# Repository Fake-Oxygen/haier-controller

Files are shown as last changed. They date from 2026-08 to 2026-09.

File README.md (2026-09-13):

# Haier Heat Pump Controller

Custom controller and monitoring interface for Haier heat pumps using the **YR-E27 remote-control interface / Modbus RTU**.

The project combines an embedded controller, custom hardware, firmware, and host-side tools for communicating with and monitoring the heat pump.

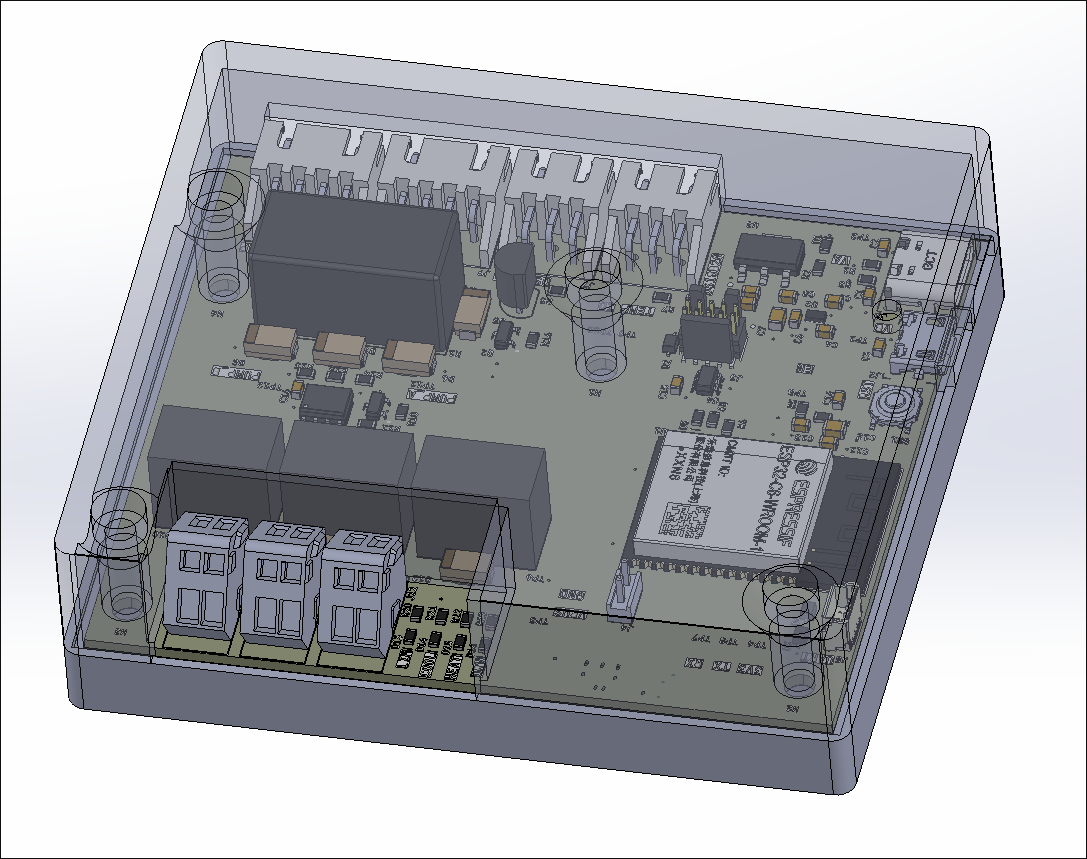
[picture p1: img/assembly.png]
Assembly


## Overview

The controller interfaces directly with the heat pump's communication bus and provides access to operational data and control parameters that are otherwise handled by the original control system.

The system is built around an **ESP32-C6** running **Zephyr RTOS**. The controller communicates with the heat pump over UART/Modbus RTU and exposes selected telemetry and control functionality through Wi-Fi and MQTT.

The repository also contains hardware and mechanical design files, as well as software utilities used for protocol investigation, testing, and monitoring.

## System Architecture

```text
                    ┌─────────────────────┐
                    │    Haier Heat Pump  │
                    │                     │
                    │  YR-E27 / Modbus RTU│
                    └──────────┬──────────┘
                               │
                         UART / RS-485
                               │
                    ┌──────────▼──────────┐
                    │   ESP32-C6          │
                    │                     │
                    │   Zephyr RTOS       │
                    │   Modbus client     │
                    │   Heat pump driver  │
                    │   Control logic     │
                    └───────┬───────┬─────┘
                            │       │
                          Wi-Fi    GPIO
                            │       │
                     ┌──────▼───┐   ├── Relay outputs
                     │   MQTT   │   └── Status / sensors
                     └──────────┘
```

The exact hardware interfaces and signal routing are documented in the hardware design files.

## Heat Pump Communication

The main purpose of the project is direct communication with the Haier heat pump.

Communication uses **Modbus RTU over UART**. The firmware implements the required register access and translates the heat pump's register data into higher-level operating parameters.

The implementation currently provides access to parameters including:

* CH temperature
* DHW temperature
* CH target temperature
* DHW target temperature
* Operating mode
* Valve state
* Tank status
* Heater operating state
* Other system status registers

The firmware can also write supported registers to change selected operating parameters.

The register definitions and protocol implementation are located in the firmware sources.

## Hardware

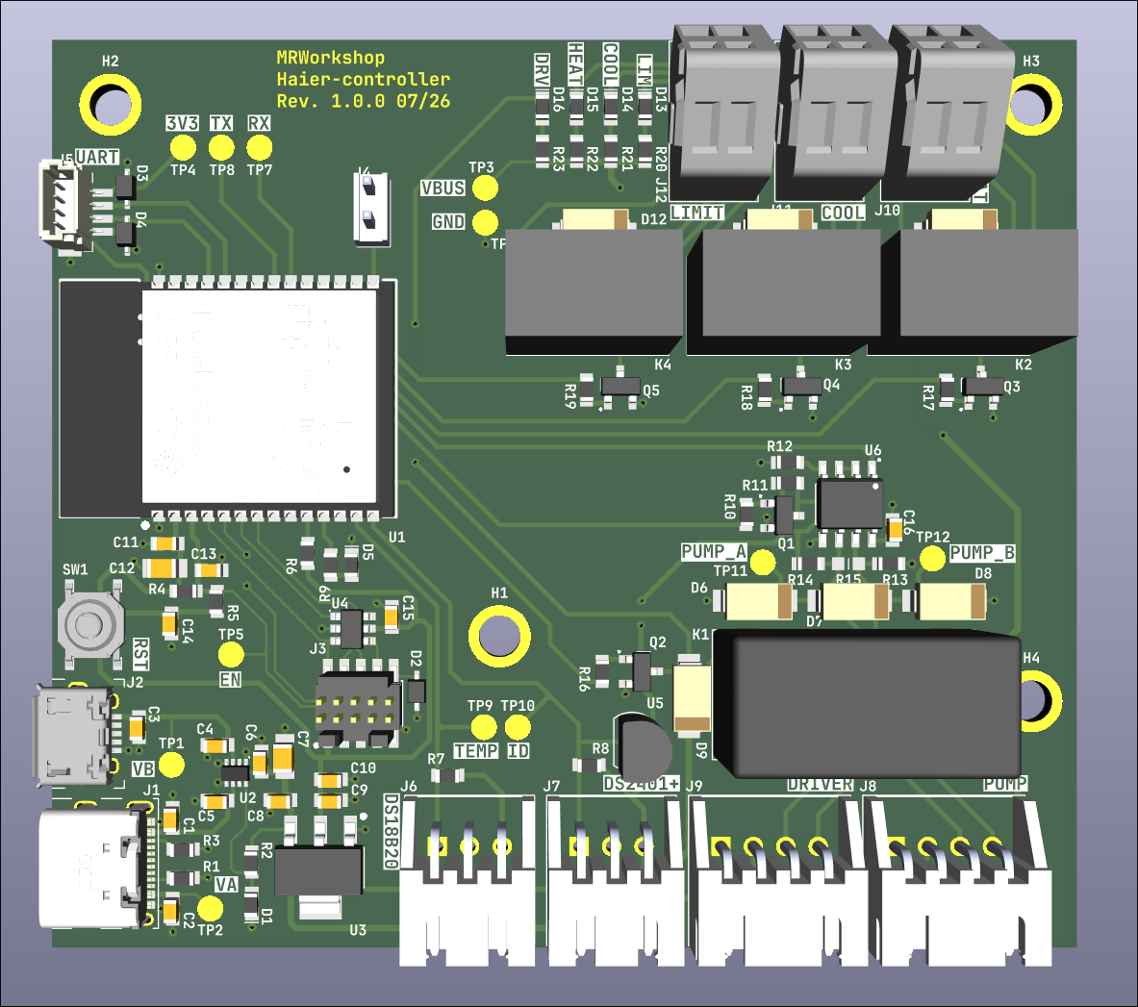
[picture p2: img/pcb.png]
PCB


The controller is based on an **ESP32-C6**.

The hardware provides interfaces for:

* Heat pump communication
* Wi-Fi
* Temperature measurement
* Relay/control outputs
* Status indication

The complete hardware design is located in [`hw/`](./hw).

Refer to the schematics and PCB files there for the actual electrical implementation.

## Mechanical Design

Mechanical parts and enclosure designs are located in [`hwm/`](./hwm).

The enclosure is designed around the controller hardware and its intended installation environment.

Available CAD/manufacturing files should be treated as the authoritative source for dimensions and mechanical details.

## Firmware

The embedded firmware is located in [`fw/`](./fw).

It is written in **C** and uses **Zephyr RTOS**.

The firmware is responsible for:

* Modbus communication with the heat pump
* Register decoding
* Heat pump state/control handling
* Wi-Fi connectivity
* MQTT communication
* Telemetry publishing
* Local I/O such as relays and sensors

The main application and hardware-specific code are organized within the firmware tree.

## MQTT

The controller publishes heat pump telemetry over MQTT, allowing the data to be consumed by external systems such as home-automation or monitoring software.

Telemetry is encoded using **CBOR** before being published.

The MQTT interface is implemented in the firmware and is intended to decouple the heat pump interface from higher-level monitoring and automation systems.

## Host-Side Tools

The [`sw/`](./sw) directory contains software used during development and operation of the system.

These tools are separate from the ESP32 firmware and are useful for tasks such as:

* Monitoring communication
* Testing the heat pump interface
* Experimenting with the protocol
* Simulating heat pump behavior

In particular, `sniffer.py` and `mock_heatpump.py` are used for working with the communication protocol without necessarily relying on the complete embedded system.

## Building the Firmware

The firmware uses the Zephyr build system and `west`.

Initialize the project:

```bash
./init.sh
```

Build for the target board:

```bash
west build -p auto -b esp32c6_devkitc_hpcore
```

Flash the resulting firmware:

```bash
west flash
```

The required Zephyr SDK and Python dependencies must be installed before building.

## Repository Structure

```text
.
├── fw/                  # ESP32-C6 firmware
│   ├── src/             # Application code
│   ├── drivers/         # Hardware / heat pump drivers
│   └── boards/          # Board-specific configuration
│
├── hw/                  # Electronics design
│   ├── ...              # Schematics / PCB files
│   └── ...
│
├── hwm/                 # Mechanical design
│   ├── ...              # CAD / STL files
│   └── ...
│
├── sw/                  # Host-side tools
│   ├── sniffer.py       # Protocol analysis tool
│   ├── mock_heatpump.py # Heat pump simulator
│   └── ...
│
└── README.md
```

## Development Status

This repository contains an actively developed controller and reverse-engineering effort for interfacing with the Haier heat pump communication system.

The firmware, hardware, and host-side tooling are maintained together because development of the controller depends on understanding and testing the heat pump's communication protocol.

For the current implementation status, refer to the firmware and software sources rather than assuming that every documented interface is production-ready.

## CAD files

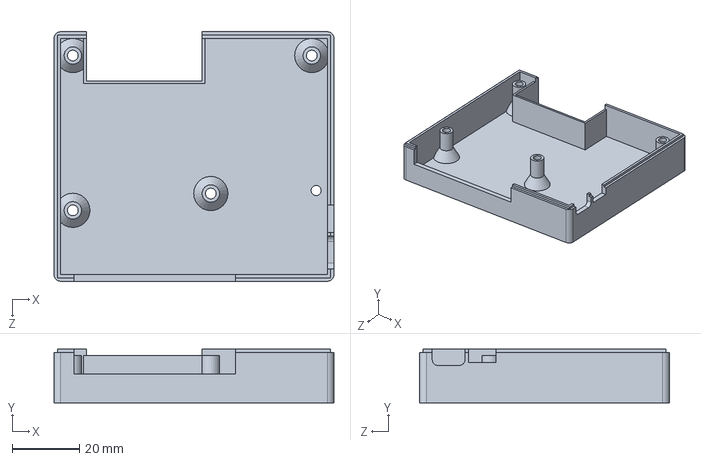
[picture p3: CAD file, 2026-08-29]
hwm/enclosure-top.SLDPRT
83.2 x 15.9 x 74.2 mm

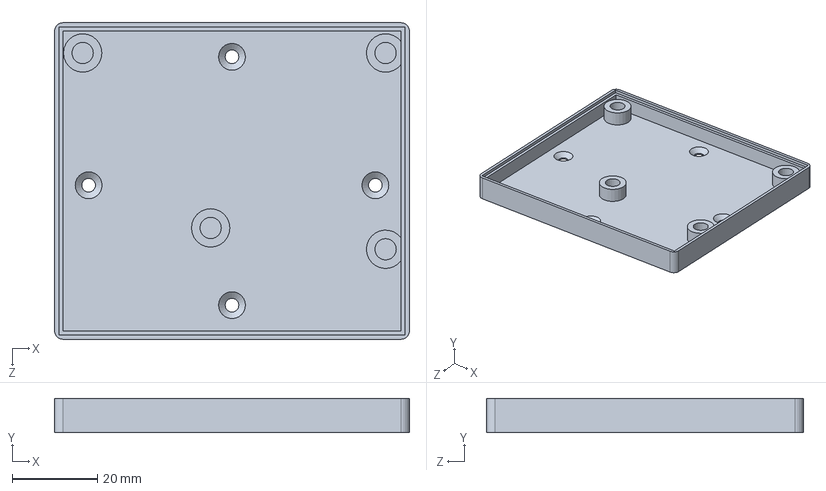
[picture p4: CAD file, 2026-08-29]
hwm/enclosure-bot.SLDPRT
83.2 x 8.00 x 74.2 mm

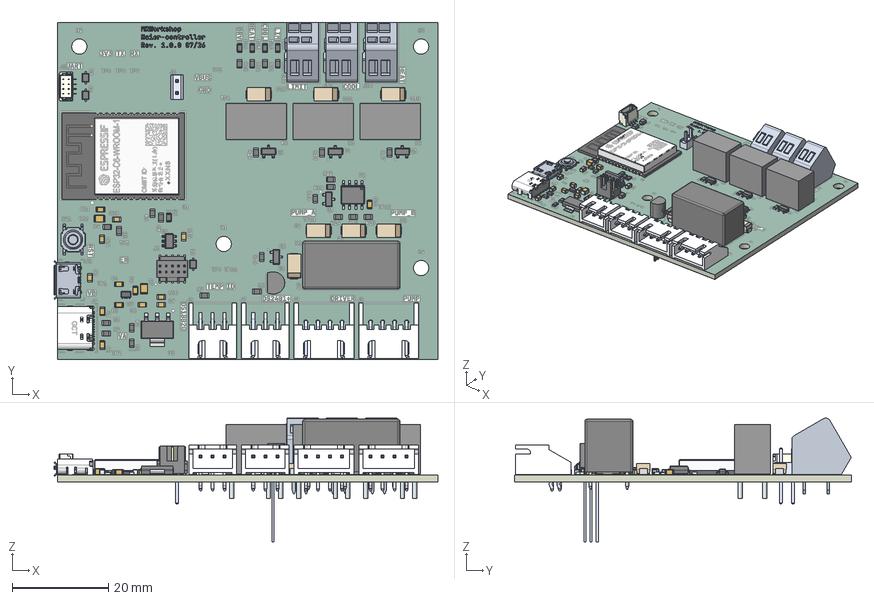
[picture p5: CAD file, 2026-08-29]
hwm/haier-controller-pcb.step
79.8 x 70.0 x 25.7 mm
PCB x 56
Mid Body x 23
Mark x 23
BODY-SOT
Goldpin 2.54 1x2 Vertical
Leader x 29
10118194C
SxB-XH-A_3 x 2
pin^SxB-XH-A ass_bent x 4
pin^SxB-XH-A ass x 2
Leads x 18
BM04B-SRSS-TB(LF)(SN)-PIN
BM04B-SRSS-TB(LF)(SN)-BODY
lead x 6
ESP32-C6-WROOM-1U-N4
DS2401+
Lead x 3
Tab
SxB-XH-Axxxxx_4 x 2
pin^SxB-XH-A-1(LF)(SN)_bent x 4
pin^SxB-XH-A-1(LF)(SN) x 4
HSG_Ĭɏ
FTSH-105-01-L-DV-K
HFD27 005-H
haier-controller-unsaved-export-n6KFfo_silkscreen
haier-controller-unsaved-export-n6KFfo_soldermask x 2
haier-controller-unsaved-export-n6KFfo_PCB

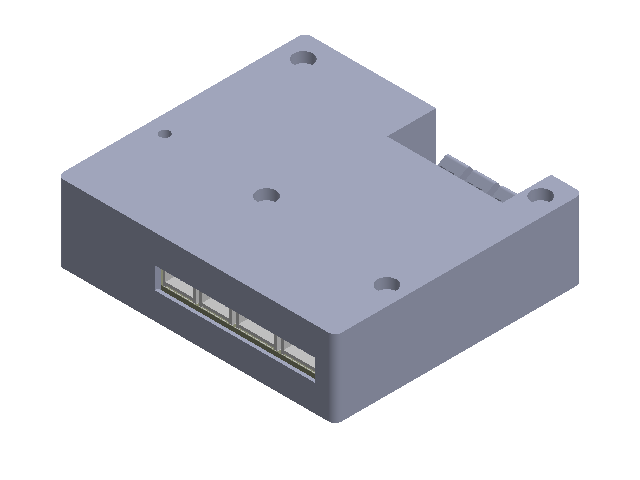
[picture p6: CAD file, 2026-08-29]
hwm/Assembly.SLDASM
enclosure-bot
Mid Body.step x 23
Mark.step x 23
SOLID.step
SOLID-0.step
SOLID-1.step
SOLID-2.step
SOLID-3.step
SOLID-4.step
SOLID-5.step
SOLID-6.step
BODY-SOT.step
Goldpin 2.54 1x2 Vertical-7.step
Leader.step x 15
10118194C.step
part.step x 7
SxB-XH-A_3.step x 2
pin_SxB-XH-A ass_bent.step x 4
pin_SxB-XH-A ass.step x 2
2.step x 3
Body-9.step x 3
Leads.step x 18
1.step
Leader-13.step x 6
BM04B-SRSS-TB(LF)(SN)-PIN.step
BM04B-SRSS-TB(LF)(SN)-BODY.step
lead.step x 6
ESP32-C6-WROOM-1U-N4-14.step
DS2401+.step
Lead_1.step x 3
Tab.step
Leader-15.step x 8
SxB-XH-Axxxxx_4.step x 2
pin_SxB-XH-A-1(LF)(SN)_bent.step x 4
pin_SxB-XH-A-1(LF)(SN).step x 4
HSG_____.step
Shell_0.95.step
FTSH-105-01-L-DV-K-16.step
HFD27 005-H.step
haier-controller-unsaved-export-n6KFfo_silkscreen.step
haier-controller-unsaved-export-n6KFfo_soldermask.step
haier-controller-unsaved-export-n6KFfo_soldermask-17.step
haier-controller-unsaved-export-n6KFfo_PCB.step
enclosure-top

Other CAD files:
hwm/STL/enclosure-bot.STL
hwm/STL/enclosure-top.STL
hwm/haier-controller-pcb.SLDASM

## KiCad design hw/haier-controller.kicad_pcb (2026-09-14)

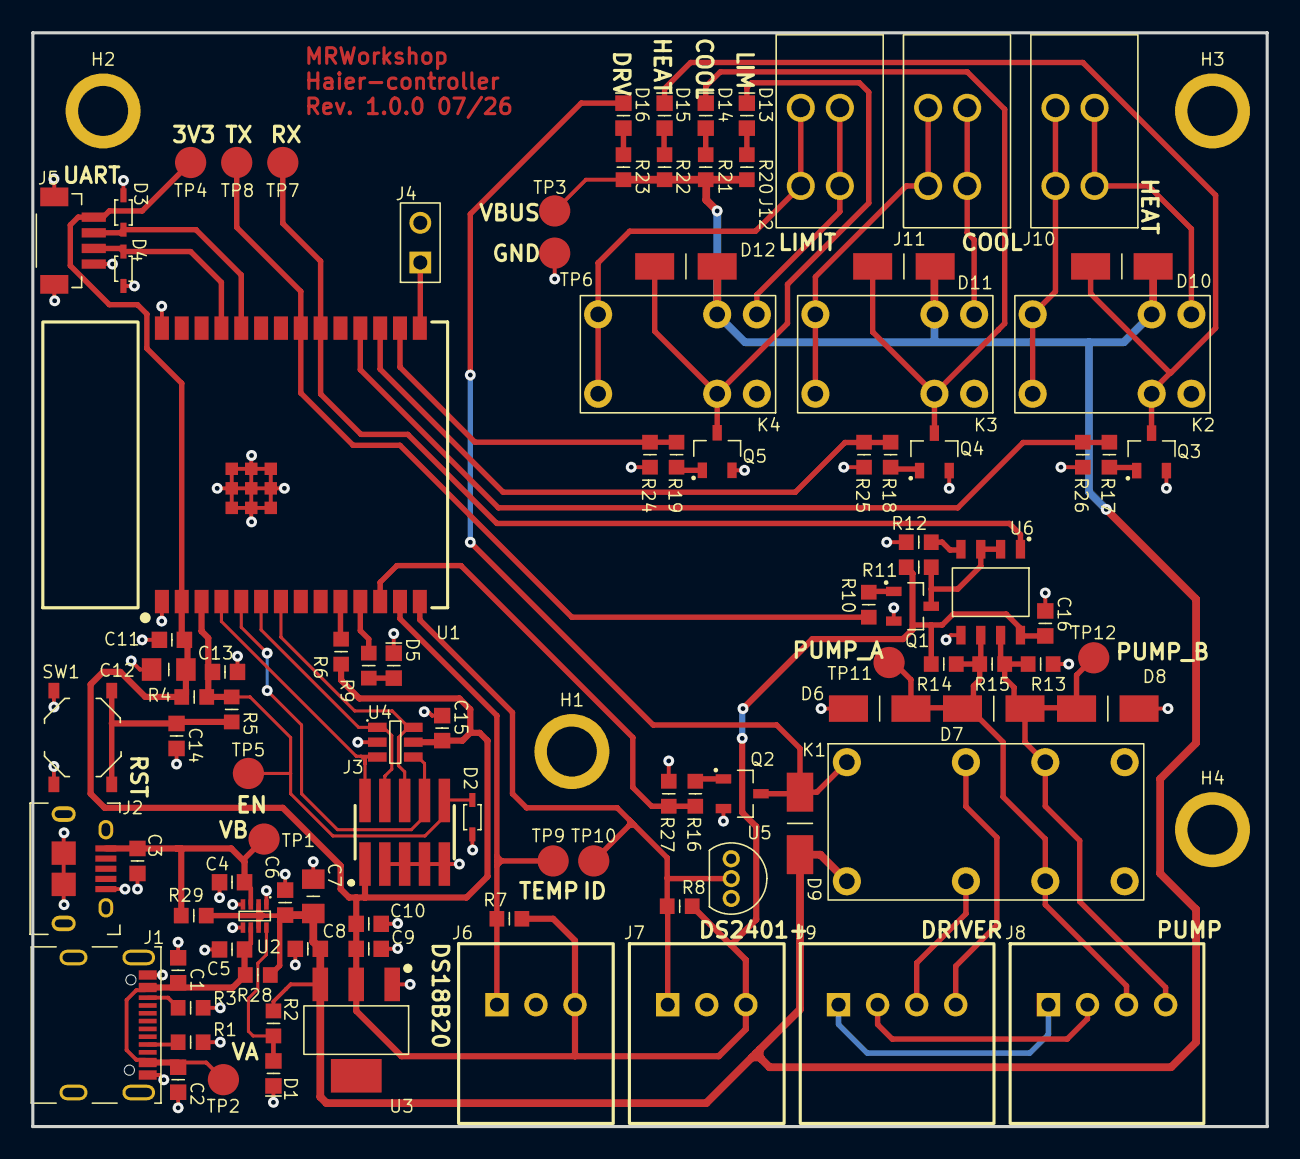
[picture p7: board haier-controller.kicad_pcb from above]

Board: 2 copper layers, 79.0 x 70.0 mm, 105 parts (0 on the bottom side), 55 nets.

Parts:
C1, C2, C3, C13: 1u; C_0603
C4, C5, C6, C8, C9, C11, C14, C15, C16: 100n; C_0603
C7: 10u; C_0805
C10: 10u; C_0603
C12: 22uF; C_0805
D1, D5, D13, D14, D15, D16: Green; LED_0603
D2, D3, D4: STS321033B100; SOD-323
D6, D7, D8: SMAJ12CA-13-F; SMA
D9, D10, D11, D12: M7; SMA
H1, H2, H3, H4: M3; M3-Hole
J1: USB4105-GF-A
J2: 10118194-0001LF
J3: FTSH-105-01-L-DV-K
J4: Goldpin; Goldpin 2.54mm 1x2 Vertical
J5: BM04B; BM04B-SRSS-TB (LF)(SN)
J6, J7: S3B-XH-A-1; S3B-XH-A-1 (LF)(SN)
J8, J9: S4B-XH-A-1; S4B-XH-A-1 (LF)(SN)
J10, J11, J12: DG240W; DG240W-2.54-02P-15-00A(H)
K1: HFD27-005-S
K2, K3, K4: HFD23/005-1ZS; HFD23-005-1ZS
Q1, Q2, Q3, Q4, Q5: MMBT3904; SOT-23
R1, R3: 5k1; R_0603
R2, R9, R16, R17, R18, R19, R20, R21, R22, R23: 1k; R_0603
R4, R6, R24, R25, R26, R27: 10k; R_0603
R5, R12, R28, R29: 0R; R_0603
R7, R8, R10, R11, R13, R14: 4k7; R_0603
R15: 120R; R_0603
SW1: PTS526SM15SMTR2_LFS
TP1, TP2, TP3, TP4, TP5, TP6, TP7, TP8, TP9, TP10, TP11, TP12: TestPoint-2mm
U1: ESP32-C6; ESP32-C6-WROOM-1
U2: LM66200DRLR; SOT8
U3: LD1117S33CTR; SOT-223
U4: USBLC6-4SC6; SOT23-6L
U5: DS2401+; TO-92
U6: MAX3485EESA+T; SO8

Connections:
+3.3V: C9.2, C10.2, C11.2, C12.2, C15.2, C16.1, J3.1 (VREF), J5.1, J6.3, J7.3, R4.1, R6.2, R7.1, R8.1, R11.1, R14.1, TP4.1, U1.2 (3V3), U3.2 (VOUT), U4.5 (VBUS), U6.8 (VCC)
/1W_ID: J7.1, R8.2, TP10.1, U1.14 (IO13), U5.2 (DATA)
/COOL_SW: R18.2, R25.2, U1.17 (IO19)
/DRV_A: J9.3, K1.7 (NC2)
/DRV_B: J9.4, K1.2 (NC1)
/DS18B20: J6.1, R7.2, TP9.1, U1.13 (IO12)
/ESP_EN: C13.2, D2.2, J3.10 (RST), R4.2, R5.1, TP5.1, U1.3 (EN)
/ESP_TCK: J3.4 (TCK/SWDCLK), U1.6 (IO6), U4.1 (I/O1)
/ESP_TDI: J3.8 (TDI), U1.5 (IO5), U4.4 (I/O3)
/ESP_TDO: J3.6 (TDO/SWO), U1.7 (IO7), U4.6 (I/O4)
/ESP_TMS: J3.2 (TMS/SWDIO), U1.4 (IO4), U4.3 (I/O2)
/HEAT_SW: R17.2, R26.2, U1.18 (IO20)
/LIM_SW: R19.2, R24.2, U1.16 (IO18)
/PUMP_A: D6.1, D7.2, J8.3, K1.6 (COM2), R14.2, R15.1, TP11.1, U6.6 (A)
/PUMP_B: D7.1, D8.2, J8.4, K1.3 (COM1), R13.1, R15.2, TP12.1, U6.7 (B)
/PUMP_RX: TP7.1, U1.20 (IO22), U6.1 (RO)
/PUMP_TX: R10.1, TP8.1, U1.21 (IO23)
/RS_SWITCH: R16.2, R27.2, U1.12 (IO11)
GND: C1.1, C2.1, C3.1, C4.1, C5.1, C6.1, C7.1, C8.1, C9.1, C10.1, C11.1, C12.1, C13.1, C14.1, C15.1, C16.2, D1.1, D2.1, D3.1, D4.1, D5.1, D6.2, D8.1, H1.1, H2.1, H3.1, H4.1, J1.A1 (GND), J1.A12 (GND), J1.SH (Shield), J2.5 (GND), J2.SH, J3.3 (GND), J3.5 (GND), J3.7 (VDD), J3.9 (GND), J4.2, J5.4, J5.SH, J6.2, J7.2, Q1.3 (E), Q2.3 (E), Q3.3 (E), Q4.3 (E), Q5.3 (E), R1.1, R3.1, R12.2, R13.2, R24.1, R25.1, R26.1, R27.1, SW1.2, TP6.1, U1.1 (GND), U1.28 (GND), U1.29 (EPAD), U2.1 (GND), U2.4 (~ON), U2.5 (GND), U3.1 (GND), U4.2 (GND), U5.1 (GND), U6.5 (GND)
unnamed: C14.2, R5.2, SW1.1
unnamed: D5.2, R9.1
unnamed: D13.2, R20.2
unnamed: D14.2, R21.2
unnamed: D15.2, R22.2
unnamed: D16.2, R23.2
unnamed: J1.A5 (CC1), R3.2
unnamed: J1.B5 (CC2), R1.2
unnamed: J8.1, J9.1
unnamed: J8.2, J9.2
unnamed: J10.2, K2.3 (COM1), K2.4 (COM1)
unnamed: J11.2, K3.3 (COM1), K3.4 (COM1)
unnamed: J12.2, K4.3 (COM1), K4.4 (COM1)
unnamed: D9.2, D16.1, K1.1 (VCC), Q2.2 (C)
unnamed: J10.1, K2.6 (NO1)
unnamed: D10.2, D15.1, K2.2 (VCC), Q3.2 (C)
unnamed: J11.1, K3.6 (NO1)
unnamed: D11.2, D14.1, K3.2 (VCC), Q4.2 (C)
unnamed: J12.1, K4.6 (NO1)
unnamed: D12.2, D13.1, K4.2 (VCC), Q5.2 (C)
unnamed: Q1.1 (B), R10.2
unnamed: Q1.2 (C), R11.2, U6.2 (~RE), U6.3 (DE)
unnamed: Q2.1 (B), R16.1
unnamed: Q3.1 (B), R17.1
unnamed: Q4.1 (B), R18.1
unnamed: Q5.1 (B), R19.1
unnamed: R6.1, U1.10 (IO8)
unnamed: J4.1, U1.15 (IO9)
unnamed: R9.2, U1.11 (IO10)
unnamed: D3.2, J5.2, U1.24 (RXD0)
unnamed: D4.2, J5.3, U1.25 (TXD0)
unnamed: D1.2, R2.2, U2.8 (ST)
unnamed: R12.1, U6.4 (DI)
VBUS: C6.2, C7.2, C8.2, D9.1, D10.1, D11.1, D12.1, K1.8 (GND), K2.5 (GND), K3.5 (GND), K4.5 (GND), R2.1, R20.1, R21.1, R22.1, R23.1, R28.1, R29.1, TP3.1, U2.2 (VOUT), U2.7 (VOUT), U3.3 (VIN)
VBUS_A: C1.2, C2.2, C5.2, J1.A4 (VBUS), J1.A9 (VBUS), R28.2, TP2.1, U2.6 (VIN2)
VBUS_B: C3.2, C4.2, J2.1 (VCC), R29.2, TP1.1, U2.3 (VIN1)

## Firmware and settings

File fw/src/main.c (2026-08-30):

#include "relay.h"
#include "zephyr/device.h"
#include <sys/errno.h>
#include <zephyr/drivers/led.h>
#include <zephyr/devicetree.h>

#include "wifi.h"
#include "zephyr/kernel.h"
#include "zephyr/logging/log.h"
#include <haierctrl/drivers/heatpump.h>
#include <zephyr/shell/shell.h>
#include "temp.h"
#include "mqtt.h"
#include "zephyr/sleep.h"
#include "haierctrl.h"

LOG_MODULE_REGISTER(heatpump, CONFIG_LOG_DEFAULT_LEVEL);

static const struct device *heatpump = DEVICE_DT_GET(DT_ALIAS(heatpump));
static const struct led_dt_spec led_0 = LED_DT_SPEC_GET(DT_NODELABEL(status_led));

void get_status(struct status_packet *packet) {
  float ti, to;
  heatpump_read_twi_two(heatpump, &ti, &to);
  struct heatpump_status stat;
  heatpump_read_status(heatpump, &stat);
  packet->ambient_temp = read_temp();
  packet->ch_temp = ti;
  packet->dhw_temp = heatpump_read_dhw_temp(heatpump);
  packet->ch_target_temp = heatpump_read_ch_temp(heatpump);
  packet->dhw_target_temp = heatpump_read_dhw_target_temp(heatpump);
  packet->opr_mode = heatpump_read_mode(heatpump);
  packet->tank_state = stat.has_tank;
  packet->heater_state = stat.heat_mode;
  packet->driver_state = stat.is_on;
  packet->valve_state = heatpump_get_3way(heatpump);
}

int main() {
  relay_init();
  temp_init();
  wifi_init();
  wifi_connect(CONFIG_WIFI_CREDENTIALS_STATIC_SSID, CONFIG_WIFI_CREDENTIALS_STATIC_PASSWORD);
  wifi_wait_for_ip_addr();
  mqtt_init(BROKER_IP);
  while(1) {
    led_on_dt(&led_0);
    struct status_packet packet;
    get_status(&packet);
    publish_status(&packet);
    led_off_dt(&led_0);
    k_sleep(K_SECONDS(30));
  }
}

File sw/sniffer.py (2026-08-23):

import logging
import serial
import time

# --- Configuration ---
PORT = "/dev/ttyUSB1"  # USB-to-RS485 adapter port
BAUDRATE = 9600
SLAVE_ADDR_HEX = "11"  # Slave ID 17 in Hex

logging.basicConfig(
    level=logging.INFO, format="%(asctime)s [%(levelname)s] %(message)s"
)

# Global variables to store parsed registers
R101, D101 = [], []
R141, D141 = [], []
R201 = []
R241, D241 = [], []


def get_ch_temp(payload):
    """Central heating temperature display function."""
    if len(payload) == 6:
        chtemp = int(hex(payload[1])[2:4], 16) / 2.0
        return chtemp
    return "Bad payload length"


def read_pump(ser):
    global R101, D101, R141, D141, R201, R241, D241

    logging.info(f"Sniffer active on {PORT} @ {BAUDRATE}-8-E-1...")

    while True:
        if not ser.is_open:
            logging.error("Serial connection closed.")
            break

        try:
            # Read 1 byte and check for target Slave ID (0x11 / 17)
            raw_byte = ser.read(1)
            if not raw_byte:
                continue

            rs = raw_byte.hex()

            if rs == SLAVE_ADDR_HEX:
                # Read function code / header (2 bytes)
                func_header = ser.read(2).hex()

                # --- Handle Write Commands (Function Code 0x10) ---
                if func_header == "1000":
                    header_bytes = ser.read(8).hex()
                    byte_len_hex = header_bytes[-2:]
                    byte_len = int(byte_len_hex, 16)
                    write_data = ser.read(byte_len).hex()

                    full_frame = "111000" + header_bytes + write_data
                    formatted = " ".join(
                        full_frame[i : i + 2]
                        for i in range(0, len(full_frame), 2)
                    )
                    logging.info(f"[WRITE CAPTURED] {formatted}")

                # --- Handle Read Responses (Function Code 0x03) ---

                # R101 Response (6 registers = 12 bytes = 0x0c)
                elif func_header == "030c":
                    R101, D101 = [], []
                    for _ in range(6):
                        val_hex = ser.read(2).hex()
                        if val_hex:
                            val_int = int(val_hex, 16)
                            R101.append(val_int)
                            m, l = divmod(val_int, 256)
                            D101.extend([m, l])

                    ch_temp = get_ch_temp(R101)
                    logging.info(f"[R101] Data: {D101} | CH Temp: {ch_temp}°C")

                # R141 Response (16 registers = 32 bytes = 0x20)
                elif func_header == "0320":
                    R141, D141 = [], []
                    for _ in range(16):
                        val_hex = ser.read(2).hex()
                        if val_hex:
                            val_int = int(val_hex, 16)
                            R141.append(val_int)
                            m, l = divmod(val_int, 256)
                            D141.extend([m, l])

                    logging.info(f"[R141] Data: {D141}")

                # R201 Response (1 register = 2 bytes = 0x02)
                elif func_header == "0302":
                    R201 = []
                    val_hex = ser.read(2).hex()
                    if val_hex:
                        R201.append(int(val_hex, 16))

                    logging.info(f"[R201] Data: {R201}")

                # R241 Response (22 registers = 44 bytes = 0x2c)
                elif func_header == "032c":
                    R241, D241 = [], []
                    for _ in range(22):
                        val_hex = ser.read(2).hex()
                        if val_hex:
                            val_int = int(val_hex, 16)
                            R241.append(val_int)
                            m, l = divmod(val_int, 256)
                            D241.extend([m, l])

                    logging.info(f"[R241] Data: {D241}")

        except Exception as e:
            logging.error(f"Error reading bus: {e}")
            break


def main():
    try:
        ser = serial.Serial(
            port=PORT,
            baudrate=BAUDRATE,
            parity=serial.PARITY_EVEN,
            stopbits=serial.STOPBITS_ONE,
            bytesize=serial.EIGHTBITS,
            timeout=1,
        )
    except Exception as e:
        logging.error(f"Could not open port {PORT}: {e}")
        return

    try:
        read_pump(ser)
    except KeyboardInterrupt:
        logging.info("Sniffer stopped by user.")
    finally:
        ser.close()


if __name__ == "__main__":
    main()

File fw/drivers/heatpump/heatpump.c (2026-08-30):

#include "haier_cmd.h"
#include "zephyr/device.h"
#include "zephyr/drivers/gpio.h"
#include "zephyr/drivers/uart.h"
#include "zephyr/kernel.h"
#include "zephyr/modbus/modbus.h"
#include "zephyr/sleep.h"
#include "zephyr/sys/clock.h"
#include "zephyr/sys/time_units.h"
#include <stdbool.h>
#include <stddef.h>
#include <stdint.h>
#include <stdio.h>
#include <string.h>
#include <sys/errno.h>
#include <zephyr/devicetree.h>
#include <zephyr/logging/log.h>
#include <zephyr/logging/log_core.h>

#include <haierctrl/drivers/heatpump.h>

#define DT_DRV_COMPAT haier_heatpump
LOG_MODULE_REGISTER(heatpump_driver, CONFIG_LOG_DEFAULT_LEVEL);

K_MUTEX_DEFINE(data_mutex);
K_SEM_DEFINE(write_sem, 0, 1);

struct write_request {
  bool pending;
  bool transmitting;
};

static struct write_request write_req_data;

static int write_pump(const struct device *dev, uint16_t addr, uint16_t *regs, size_t len) {
  const struct heatpump_config *cfg = dev->config;
  const struct heatpump_data *data = dev->data;
  if(data->modbus_client_iface < 0)
    return -EINVAL;
  
  k_sem_reset(&write_sem);
  write_req_data.pending = true;

  LOG_INF("Waiting for write semaphore");
  if(k_sem_take(&write_sem, K_MSEC(5000)) != 0) {
    LOG_ERR("Write timeout");
    write_req_data.pending = false;
    return -ETIMEDOUT;
  }
  
  write_req_data.transmitting = true;
  gpio_pin_set_dt(&cfg->enable_gpio, 1);
  k_msleep(1000);
  int err = modbus_write_holding_regs(data->modbus_client_iface, cfg->slave_addr, addr, regs, len);
  k_msleep(200);
  gpio_pin_set_dt(&cfg->enable_gpio, 0);
  write_req_data.pending = false;
  write_req_data.transmitting = false;
  return err;
}

static bool uart_read_bytes(const struct device *dev, uint8_t *buf, size_t len, k_timeout_t timeout) {
  size_t read_count = 0;
  int64_t start_time = k_uptime_get();

  while(read_count < len) {
    uint8_t c;
    if(uart_poll_in(dev, &c) == 0) 
      buf[read_count++] = c;
    else 
      k_msleep(1);

    if(K_TIMEOUT_EQ(timeout, K_NO_WAIT) || (k_uptime_get() - start_time > k_ticks_to_ms_floor64(timeout.ticks)))
      break;
  }
  return (read_count == len);
}

static void parse_registers(const uint8_t *raw, uint16_t *out, size_t len) {
  for(size_t i = 0; i < len; i++)
    out[i] = (uint16_t)((raw[i * 2] << 8) | raw[i * 2 + 1]);
}

static void sniffer(void *p1, void *p2, void *p3) {
  const struct heatpump_config *cfg = p1;
  struct heatpump_data *data = p2;
  if(!device_is_ready(cfg->uart)) {
    LOG_ERR("UART device not ready!");
    return;
  }

  LOG_INF("Modbus sniffer started...");

  while(1) {
    if(write_req_data.transmitting) {
      k_msleep(100);
      continue;
    }

    uint8_t addr;
    if(!uart_read_bytes(cfg->uart, &addr, 1, K_FOREVER))
      continue;

    if(addr != cfg->slave_addr)
      continue;

    uint8_t header[2];

    if(!uart_read_bytes(cfg->uart, header, 2, K_MSEC(50)))
      continue;

    if(header[0] != 0x03)
      continue;
    
    uint8_t payload[64];
    if(header[1] > sizeof(payload))
      continue;

    if(uart_read_bytes(cfg->uart, payload, header[1], K_MSEC(100))) {
      k_mutex_lock(&data_mutex, K_FOREVER);
      // LOG_HEXDUMP_INF(header, 2, "Header");
      // LOG_HEXDUMP_INF(payload, header[1], "Payload");
      switch (header[1]) {
      case 0x0C:
        parse_registers(payload, data->registers.R101, 6);
        break;
      case 0x20:
        parse_registers(payload, data->registers.R141, 16);
        break;
      case 0x02:
        parse_registers(payload, data->registers.R201, 1);
        break;
      case 0x2C:
        parse_registers(payload, data->registers.R241, 22);
        if(write_req_data.pending) {
          LOG_INF("Giving write semaphore");
          k_sem_give(&write_sem);
          k_msleep(300);
        }
        break;
      }
      k_mutex_unlock(&data_mutex);
    }
    
  }
}

static enum heatpump_threeway get_3way(const struct device *dev) {
  struct heatpump_data *data = dev->data;
  k_mutex_lock(&data_mutex, K_FOREVER);
  enum heatpump_threeway state = get_3way_state(data->registers.R141, 16);
  k_mutex_unlock(&data_mutex);
  return state;
}

static float read_ch_temp(const struct device *dev) {
  struct heatpump_data *data = dev->data;
  float temp; 
  k_mutex_lock(&data_mutex, K_FOREVER);
  get_ch_temp(data->registers.R101, 6, &temp);
  k_mutex_unlock(&data_mutex);
  return temp;
}

static float read_dhw_temp(const struct device *dev) {
  struct heatpump_data *data = dev->data;
  float temp; 
  k_mutex_lock(&data_mutex, K_FOREVER);
  get_dhw_temp(data->registers.R141, 16, &temp);
  k_mutex_unlock(&data_mutex);
  return temp;
}

static float read_dhw_target_temp(const struct device *dev) {
  struct heatpump_data *data = dev->data;
  float temp; 
  k_mutex_lock(&data_mutex, K_FOREVER);
  get_dhw_target_temp(data->registers.R101, 6, &temp);
  k_mutex_unlock(&data_mutex);
  return temp;
}

static enum heatpump_state read_heater_state(const struct device *dev) {
  struct heatpump_data *data = dev->data;
  k_mutex_lock(&data_mutex, K_FOREVER);
  enum heatpump_state state = get_heater_state(data->registers.R141, 16);
  k_mutex_unlock(&data_mutex);
  return state;
}

static enum heatpump_mode read_mode(const struct device *dev) {
  struct heatpump_data *data = dev->data;
  k_mutex_lock(&data_mutex, K_FOREVER);
  enum heatpump_mode mode = get_mode(data->registers.R201, 1);
  k_mutex_unlock(&data_mutex);
  return mode;
}

static int read_twi_two(const struct device *dev, float *ti, float *to) {
  struct heatpump_data *data = dev->data;
  struct ti_to_info t_info;
  k_mutex_lock(&data_mutex, K_FOREVER);
  int err = get_twi_two_info(data->registers.R141, 16, &t_info);
  k_mutex_unlock(&data_mutex);
  *ti = t_info.ti;
  *to = t_info.to;
  return err;
}

static enum heatpump_state read_pump_state(const struct device *dev) {
  struct heatpump_data *data = dev->data;
  k_mutex_lock(&data_mutex, K_FOREVER);
  enum heatpump_state state = get_pump_state(data->registers.R141, 16);
  k_mutex_unlock(&data_mutex);
  return state;
}

static int read_pump_status(const struct device *dev, struct heatpump_status *stat) {
  struct heatpump_data *data = dev->data;
  k_mutex_lock(&data_mutex, K_FOREVER);
  int err = get_state(data->registers.R101, 6, stat);
  k_mutex_unlock(&data_mutex);
  return err;
}

static int set_pump_ch_temp(const struct device *dev, float temp) {
  if(temp < 6 || temp > 50)
    return -EINVAL;
  struct heatpump_data *data = dev->data;
  uint16_t regs[6];
  LOG_INF("Setting temp to %f", (double)temp);
  k_mutex_lock(&data_mutex, K_FOREVER);
  int err = set_ch_temp(data->registers.R101, 6, temp, regs);
  k_mutex_unlock(&data_mutex);
  write_pump(dev, 101, regs, 6);
  return err;
}
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

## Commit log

2026-07-05 Finished schematic
    [haier-controller.kicad_pcb, haier-controller.kicad_sch]
2026-07-10 Updated R1,R3,J3
    [haier-controller.kicad_sch]
2026-07-10 Update footprints, Import to PCB
    [haier-controller.kicad_pcb, haier-controller.kicad_sch]
2026-07-12 Finish PCB
    [haier-controller.kicad_pcb, haier-controller.kicad_sch]
2026-07-13 Clean ERC errors
    [haier-controller.kicad_pcb, haier-controller.kicad_sch]
2026-07-18 Update components, Add silkscreen descriptors
    [haier-controller.kicad_pcb, haier-controller.kicad_sch]
2026-08-23 Write pump
2026-08-23 Implement heatpump read functions
2026-08-25 Read heatpump info
2026-08-25 Write to heatpump
2026-08-27 Relay operation
2026-08-27 Temperature reading from DS18B20
2026-08-29 Update enclosure
    [Assembly.SLDASM, enclosure-bot.SLDPRT, enclosure-bot.STL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]
2026-08-30 Add driver_state field
2026-09-11 Update board metadata
    [haier-controller.kicad_pcb]
2026-09-11 Add Pull down resistors, Change USB micro to DNP, Change ROM to DNP
    [haier-controller.kicad_sch]
2026-09-14 Update PCB
    [haier-controller.kicad_pcb]
